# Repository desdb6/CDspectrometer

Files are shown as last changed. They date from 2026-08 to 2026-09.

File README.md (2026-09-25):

# CDspectrometer

A low-cost, portable circular dichroism (CD) spectrometer for measuring plasmonic chiral nanoparticles, built using a tungsten light source and a handheld CCD photospectrometer.

## Overview

Commercial CD spectrometers are dominated by a small number of manufacturers, making the technique costly and largely inaccessible to smaller laboratories, educational institutions, or field-based research. This project provides an open-source, low-cost, and easy-to-build alternative designed for daily benchtop use.

Rather than competing with the performance of high-end commercial instruments used for molecular chirality in biological systems, this design is focused on plasmonic chiral particles, prioritizing compactness, affordability, and ease of manufacturing and use.

## Repository Structure

| Folder | Contents |
|---|---|
| `Blender/` | 3D models and design files for the spectrometer housing/components |
| `STL/` | Printable STL files for 3D-printed parts |
| `CDcontrol_Python/` | Python code for device control |
| `Spectral_Composition/` | Python code for spectral data analysis |
| `Manuals/` | Build and operation manuals |
| `Experiments/` | Experimental data and test results |
| `Notes/` | Development notes |
| `LOG.md` | Project development log |

## Hardware Type

Measuring physical properties and in-lab sensors

## Keywords

Chiroptical spectroscopy, Circular dichroism, Plasmonic chiral nanoparticles

## License

This repository contains hardware designs and software, released under different open licenses:

- **Hardware designs** (`Blender/`, `STL/`) are licensed under [CERN-OHL-S 2.0](https://ohwr.org/cern_ohl_s_v2.txt). See `Blender/LICENSE` and `STL/LICENSE`.
- **Software** (`CDcontrol_Python/`, `Spectral_Composition/`) is licensed under the [MIT License](https://opensource.org/licenses/MIT). See `CDcontrol_Python/LICENSE` and `Spectral_Composition/LICENSE`.

## Citation

*(Add citation details once the associated HardwareX paper is published.)*

## Affiliation

CIC biomaGUNE, Basque Research and Technology Alliance (BRTA), Paseo Miramón 182, 20014 Donostia-San Sebastián, Gipuzkoa, Spain

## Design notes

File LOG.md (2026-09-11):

## Lab Report

### Monday 24/08/26

- 10:00 Visit: Tour Lab
- 11:30 Study components and install software
- 15:00 Make components list
- 15:30 Try to install Kinesis on CIC laptop, didn't work
- 17:30 Look in laser room for components
- 18:00 Test assembly

#### Notes

### Tuesday 25/08/26

- 9:00 3D print training
- 10:00 Try to install Kinesis on CIC laptop, works
- 11:00 Simple Python script to control motor
- 12:00 Fix spectrometer dlls
- 14:00 Design motor holder
- 15:30 Print holder motor
- 17:00 Work on spectral composition simulation

#### Notes

##### SDK software

The provided SDK example for the spectrometer is not working, I had to replace the dll file with the one installed with the SM32pro software. Also the provided code had to be debugged. The dll is 32 bit, so we need to use 32 bit Python, for which Python 3.11.7 is best. We also need to install compatible numpy (1.26.4), kiwisolver (1.4.7) and matplotlib (3.7.5) versions.

##### Spectral composition simulation

Spectral composition simulation is best done with Mueller calculus/matrices. There is no intensity graph for the light source, so model as a blackbody curve?

### Wednesday 26/08/2026

- 9:00 Design motor holder v2
- 11:30 Print motor holder v2
- 12:00 Read spectrometer software manual
- 13:00 Visit: Laser scattering experiment to determine particle population size via Brownian motion
- 14:00 Design cuvette holder
- 16:00 Write code to control spectrometer  
- 17:00 Work on spectral composition simulation

#### Notes

##### 3D printer holder

I have removed one of the walls as it was not actually supporting the motor.
  
#### Spectrometer software

It needs a light source pointed directly into the fiber, otherwise it is just random noise and increasing the integration time does nothing.

### Thursday 27/08/2026

- 9:00 Book 3D printer
- 9:10 Figure out spectrometer code example
- 10:15 Print cuvette holder
- 10:30 Continue spectrometer code example study
- 11:30 Visit: Laser scattering experiment to determine particle population size via Brownian motion
- 11:45 Continue spectrometer code example study
- 12:30 Write my own spectrometer control script
- 13:30 Assemble cuvette holder
- 14:45 Design cuvette holder second version
- 15:00 Print cuvette holder second version
- 15:15 Improve spectrometer control code
- 17:00 Assemble setup with new cuvette holder

#### Notes

### Friday 28/08/2026
- 9:00 Design flex collimator holder
- 10:00 Print flex collimator holder
- 10:30 Print flex collimator holder second version
- 11:00 Print flex cuvette holder
- 11:30 Design flex collimator holder on baseplate
- 12:00 Visit: Bio 3D printer

#### Notes

### Monday 31/08/2026
- 9:00 Design stronger cuvette holder
- 9:30 Print stronger cuvette holder
- 10:00 Meeting Luis
- 10:20 Brainstorm calibration ideas
- 11:00 Research printing material
- 12:00 Visit: CD spectrometer
- 13:30 Look at beam size
- 14:30 Make calibration code
- 15:00 Get calibration data from CD
- 16:00 Research enclosure
- 17:00 Design enclosure fit test print

#### Notes

##### Brainstorm what to do until light source arrives
- Calibration can be done using the Jasco CD: open the shutter and select a wavelength, then put fiber in front of beam and record a spectrum -> fit a cubic polynomial through data points
- Characterize linear polarizer and find fast axis angle using other linear polarizers
- Look at beam shape by using a second fiber and shining flash light through it before the motor
- Design an enclosure for setup in suitable material, Bionanoplasmonics has its own filaments but check with Gerard as well
- Also for cuvette holder, study what material is best (this part probably needs to be reprinted once we know the beam shape)
- Do a measurement at the Jasco CD to see how it is done

##### Optical parts 3D printing
The 3D prints ideally have to be 100% opaque. Usually, a matte black PLA is opaque enough for optical setups, there is black matte TPLA in the print room. If there is still too much scattering, options include:
- Using a specialized opaque PLA, but shipping is expensive + takes time
- Cover parts in candle soot
- Use black paper to block out light
- Use paint/spray to finish prints
- Optimize infill patterns for internal reflections

Useful blog post checking filament opacity: https://www.thingiverse.com/groups/3dp-photo/forums/general/topic:7227#google_vignette

Paper on print material opacity characterization: https://pmc.ncbi.nlm.nih.gov/articles/PMC8208549/

Github for open source optical microscope, simply uses matte black PLA: https://github.com/TadPath/PUMA

##### Open source optomechanical 3D prints
https://osf.io/9kt52/overview

https://journals.plos.org/plosone/article?id=10.1371/journal.pone.0059840

##### CCD photospectrometer calibration
We did this by basically using the Jasco CD as a monochromator, shining 10nm bandwidth light into the CCD fiber and noting the most intense pixel. The converstion from pixels to wavelengths is then done by fitting a cubic polynomial through the datapoints. The results show that the calibration hard coded into the SP python example is very wrong, and most likely not meant to be used for the SM440 photospectrometer; good that we checked this :)

### Tuesday 01/09/2026
- 9:00 Figure out time integration units
- 10:30 Print enclosure outline
- 11:15 Code live view and improve control panel buttons
- 12:30 Design enclosure fit test print second version
- 13:00 Light source arrived
- 13:30 Assembling setup
- 13:45 Testing spectrum measurements
- 15:00 Designing fast axis alignment experiment
- 17:00 Design collimator mount for light source
- 17:30 Look in LASER room for filters for fast axis alignment experiment

#### Notes

##### SP time integration units
I wrote a script to see what the conversion unit is between the inputted int time number and real time, as I couldn't make sense of it. The documentation said it is 10/3 us/count, but my script (time_int_testing.py) gives something very close to 50 us / count. I have built this into the spectrometer control script.

##### CCD dead pixel arrays
When testing the Tungsten light source, I noticed the spectrum shows a sharp dip at the same place every time, even without atmospheric interference. When shining a flash light we can see the same dip but smaller. My guess is that there are a few pixel rows with a worse quantum efficiency, or there is some other problem preventing these pixels from functioning correctly. Specifically, pixels 2046-2078 have this problem, corresponding to a spectral range of ~728nm-738nm.

##### Alignment experiment setup
We have to align the setup in at least two ways:
1. Rotation around the beam axis
2. Angle of incidence (has to be perpendicular to the surface of the optomechanical component)

Rotation around the beam axis: The fresnel rhomb retarder is difficult to align as it is not placed on a rotating mount. I think it is more practical to leave the fresnel rhomb retarder at an arbitrary angle (but near vertical), and to align the linear polariser on the motorized mount, which can be very accurately moved. We need to design an experiment where it is possible to find a maximum\minimum by changing only **one** setting (preferable the motor position).

I worked out the Mueller calculus and found a protocol that would work. We would put a second linear polariser behind the fresnel rhomb, work in the reference frame of the fast axis of the second polariser and define the angles $$\phi$$ and $$\theta$$ as the angles between the fast axes of the first linear polariser and fresnel rhomb respectively. The transmitted intensity for an unpolarised beam is then 

$$I(\theta, \phi) \propto \cos(2\theta)\cos(2(\theta-\phi))$$

We will align the two polarisers perpendicular to make the first cosine as big as possible to see big changes in intensity when changing $$\phi$$. We then make the second term zero by putting $$\phi$$ perpendicular to $$\theta$$. At this point we can simply subtract 45 degrees to put $$\phi$$ and $$\theta$$ at a 45 degree angle to make CPL.

### Wednesday 02/09/2026
- 9:00 Print front collimator holder
- 9:15 Make excel for fast axis alignment experiment
- 9:45 Setup experiment
- 10:15 Print opacity tool
- 10:30 Setup experiment
- 11:15 Print second front collimator holder
- 12:15 Visit: temporal resolution fluorescence spectrometer
- 13:00 Fast axis alignment measurements
- 14:30 3D print enclosure fit
- 17:00 Design new cuvette holder

#### Notes

##### Alignment experiment setup detector
I tried making the setup using a power and energy meter, but the noise due to temperature fluctuations seems to be too big. If I hold my hand in front of the detector or blow air, the noise is as big as 2-4x the signal. I have programmed a script (control_panel_alignment.py) to use the CCD to integrate the spectrum over a fixed range of wavelengths, which is less susceptible to noise.

Alignment to second linear polarizer: 5.1 degrees

Alignment to fresnel rhomb: 81.40 degrees

The excel crashed so I do not have the data from the first measurements anymore. I decided to automate the process in python for the data acquisition and simply look for the minimum.

### Thursday 03/09/2026
- 9:00 Print cuvette holder
- 9:30 Code broken pixel range indicator
- 10:00 Research CD formulas
- 10:30 Code absorbance and CD funtionalities
- 12:30 Debug code
- 13:30 Test measurement
- 15:00 Absorption spectra and make slides
- 16:00 Group meeting

#### Notes

##### To Do list until first prototype
In order of importance:

- Code Absorbance / CD spectrum functionalities
- Print new cuvette holder
- Design and print enclosure
- Reprint collimator holders
- Calculate/find handedness depending on angle
- Clean components

##### Absorption spectra
I tried to get some absorption spectra which look ok for the most part. I need to indicate the interval in which the light is intense enough to create a reliable signal, and also recheck the calibration as it seems to be off by around 20nm in the 700nm area. Luis provided me with minirods which show a peak at 750 on the commercial absorption spectrometer but 770nm in mine. However, the peak at 510nm lines up and the very first measurement I took did in fact show a peak at 750nm.

### Friday 03/09/2026
- 9:00 Design and print front collimator holder
- 9:45 Fix polarization convention
- 10:15 Design back collimator holder
- 10:45 CD measurement
- 11:00 Print back collimator holder
- 11:30 Beam alignment experiments (many)
- 14:30 Fabry Perot test

#### Notes
##### To Do list
- Print collimator holders to fix alignment
- Recalibrate 700nm wavelength range
- Program intensity cutoff indicator
- Measure more CD signals and look at oscillations

##### CD artefacts
Even without a sample, we get a significant CD signal. This could be cause by a number of things.

- The beam tilt: We can observe that the front collimator holder is slightly tilted which causes the beam to not travel parallel to the horizontal axis, but upwards. This could be due to removing the print from the printbed too fats which can cause warping. Later prints that were cooled down completely seemed to be aligned well. This tilt can mess with the polarization state as the incident angles for the total internal reflection will be different. Trying to align the beam gave results that are a little better in the 400-750nm range but worse around 1000nm. However trying to make the alignment worse by triyng to tilt the beam down a lot made it better overall.
- Fast axis alignment
- Dust on the linear polarizer: As the polariser turns, the beam will fall on a different spot on the polarizer which can cause differences in absorption
- There is a oscillating signal which looks to be linear with the frequency (also present without fresnel rhomb). My theory is that the beam is diffracting at the polarizer in a different way if the polarizer is horizontal and vertical, but I still need to test this.
- Fabry perot etalon somewhere

##### To Do for next week
- Clean the polarizer
- Figure out the CD artefacts
- Make program more user friendly: error handling, user guide etc
- Make icon for program
- Discuss journal?
- Design adjustable collimator holders
- Design smaller cuvette holder
- Make parts for UV-Vis absorption modular setup

### Monday 07/09/2026
- 9:00 Print front collimator holder
- 9:30 Test misalignments and figure out CD artefacts
- 10:30 Design and print fiber holder
- 11:00 Make code more user friendly
- 11:30 Rebuild setup
- 12:00 Turning collimator experiment
- 12:30 Print collimator holder
- 13:00 Make code more user friendly and make executable
- 15:00 Print fiber holder
- 15:30 Clean components
- 17:00 Realign components
- 17:30 Write user manual
- 18:00 More CD measurements

#### Notes
##### CD artefacts
I spent the morning trying and tweaking different components of the setup. The spectra I took can be found in the outputs folder for this date. Translation does not seem to make a great difference, but the rotation of the collimators seems to show a cosine-like effect on the overall intensity. This is true for **both** collimators, the front and the back. Rotating one of them also flips the CD spectra, but it is not as linear as I would have hoped. I decided to clean all the components to see if this is an improvement but for this the components also need to be realigned. In the end this did not seem to make a huge difference. Frustrating day :(

### Tuesday 08/09/2026
- 9:00 Design and print absorption spectroscopy cuvette holder
- 9:30 Rebuild setup
- 9:45 Try to recreate CD artefacts
- 11:00 Call Carlos
- 11:45 Program CD baseline correction
- 12:30 Recalibrate CCD
- 13:30 Absorption measurements
- 14:45 Print fiber holder
- 15:00 Program CD baseline correction, fix bugs, improve usability
- 15:30 Recalibration using Holmium oxide glass
- 16:00 Absorption measurements
- 16:30 Improve code usability
- 17:00 Helicoid CD measurements
- 17:30 Prepare overnight print

#### Notes
##### CD artefacts
The spectra I took can be found in the outputs folder for this date. My first idea today was to se a different polarizer and move it by hand, but this resulted in the same artefacts with a double peak, confirming the polarizer is not the problem. 

##### Call Carlos
Carlos said that it is known that the fiber position has a very big influence on the spectrum, and that it is very difficult to stabilize this. He suggests taking baseline measurements and correcting in software. Furthermore, if might be better to work in absorbance units. He also suggested a way to calibrate the CCD using a rare earth metal glass for small absorbance peaks. Finally he said we could be open to use free space light instead of fibers in the future.

### Wednesday 09/09/2026
- 9:00 Print cuvette holder
- 9:30 Figure sign flip out
- 11:00 Print cuvette holder
- 12:00 Helicoid CD measurements
- 13:00 Compare to Jasco CD
- 15:00 Compare data to Huu-Quang
- 15:30 Reduce noise in setup
- 17:30 Prepare overnight print

#### Notes

### Thursday 10/09/2026
- 9:00 (re-)Build absorbance and CD setups
- 9:30 Print collimator holder
- 10:00 Make plot buttons better
- 11:00 Cysteine CD measurements
- 11:30 Helicoid dilution experiment
- 12:30 Make group meeting slides
- 14:00 Absorption dilution experiment
- 16:00 Group meeting
- 17:00 Fix absorption baseline issue

#### Notes
##### Helicoid dilution experiment
To test the limit of what can be measured I will perform an experiment where I dilute the helicoid samples and see if I can still measure a CD signal. I will do dilutions of 1x, 5x, 25x and 125x. I do this by preparing dilutions by pipetting 30mul of the undiluted helicoids in a cuvette with 120mul of 1mM CTAB. Then I repeat this process 2 more times to make the other dilutions, making sure the sample is homogenous every time. I will take a baseline measurement before each CD measurement.

### Friday 11/09/2026
- 9:00 Final code changes

#### Notes
##### Pyinstaller command
"C:\Users\lguser\AppData\Local\Programs\Python\Python311-32\python.exe" -m PyInstaller --onefile --windowed --icon=cd.ico --add-data "SP_SDK;SP_SDK" main.py

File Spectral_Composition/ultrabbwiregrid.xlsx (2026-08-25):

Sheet: Transmission
 |  | Ultra Broadband Wire Grid Polarizers
 |  |  | Transmission (%)
 |  | Wavelength (nm) | Parallel | Perpendicular
 |  | 250 | 37.8124 | 0.80363
 |  | 251 | 38.88543 | 0.82579
 |  | 252 | 39.89029 | 0.83728
 |  | 253 | 40.83456 | 0.83963
Product Raw Data |  | 254 | 41.72528 | 0.83425
Wire Grid Polarizers: 300 nm - 3.2 µm |  | 255 | 42.56894 | 0.82242
 |  | 256 | 43.37153 | 0.80533
Item # | WPXXX-UB1 | 257 | 44.13853 | 0.78405
DISCLAIMER: The data presented here are typical. Slight variations in performance data will occur from lot to lot. Please contact Technical Support with any questions regarding the use or reliability of this data. |  | 258 | 44.87497 | 0.75956
 |  | 259 | 45.58542 | 0.73276
 |  | 260 | 46.27402 | 0.70444
 |  | 261 | 46.94451 | 0.6753
 |  | 262 | 47.60026 | 0.64599
 |  | 263 | 48.24424 | 0.61706
This data may be used in publications. However, please cite Thorlabs as the source. |  | 264 | 48.87909 | 0.58899
 |  | 265 | 49.50713 | 0.5622
 |  | 266 | 50.13036 | 0.53705
Additional Information: |  | 267 | 50.7505 | 0.51383
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

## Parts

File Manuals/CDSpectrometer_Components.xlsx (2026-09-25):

Product | Brand + model | Link | Comments
Light source | Sarspec LS-W14 Tungsten-Halogen Light Source | https://www.sarspec.com/products/light-sources/tungsten
Fibers | Sarspec Optical Fibers | https://www.sarspec.com/store/p/optical-fibers | I am unsure about the exact specifications (wavelength range, core diameter). We used two 100cm fibers, but shorter fibers would be more convenient.
Motorized mount | Thorlabs K10CR2/M Motorized Rotation Mount | https://www.thorlabs.com/item/K10CR2_M
Linear polarizer | Thorlabs WP25M-UB1 Mounted Wire Grid Polarizer | https://www.thorlabs.com/item/WP25M-UB1?aID=82b8f769d23edb5df1b9a876879e037c&aC=2
Fresnel rhomb | Thorlabs FR600QM Mounted Quarter-Wave Fresnel Rhomb Retarder | https://www.thorlabs.com/item/FR600QM?aID=6370abdd5eea46aaf2b5422b807dee97&aC=2
Collimators | BWTEK CLA-SMA Collimating Lens Assembly | https://m-oem.myshopify.com/products/collimating-lens-assembly-br-cla-sma | I am not sure if this is the website where the collimators where ordered from.
CCD photospectrometer | Spectral Products SM440 Handheld CCD Spectrometer | https://www.spectralproducts.com/SM240_440 | This was an old photospectrometer that the lab already had. Designing software for this spectrometer was challenging becuase it lacked documentation, but I have a working program now.
Breadboard | Thorlabs Solid Aluminum Optical Breadboards | https://www.thorlabs.com/solid-aluminum-optical-breadboards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
Fresnel rhomb mount | Thorlabs LMR1/M Lens Mount with Retaining Ring | https://www.thorlabs.com/item/LMR1_M?aID=360e756541fa952e6a85bb99a7f4f247&aC=2 | Was already in the lab
Retaining rings | Thorlabs SM1RR Retaining Ring | https://www.thorlabs.com/item/SM1RR | Was already in the lab
Optical post | Thorlabs TR30/M Optical Post | https://www.thorlabs.com/item/TR30_M?aID=8e9e7e1c5f374476b27a6275a6b0f033&aC=2 | Was already in the lab, unsure about exact height
Optical post mounting base | Thorlabs BA1/M Mounting Base | https://www.thorlabs.com/item/BA1_M | Was already in the lab

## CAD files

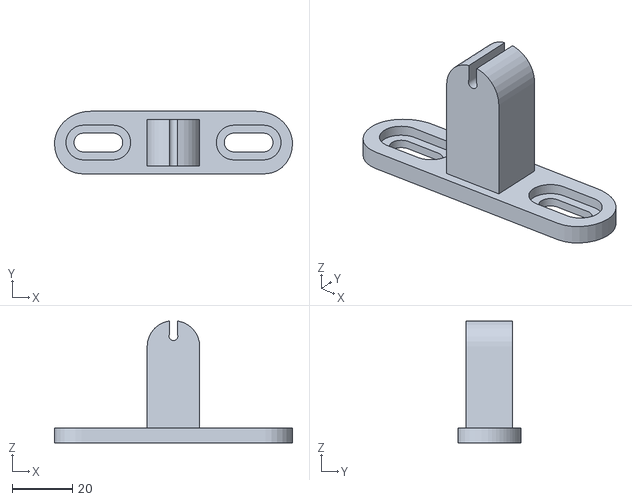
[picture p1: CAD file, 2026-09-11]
STL/20260910_UE3_Des_De_Borger_Fiber_Holder_Back_v2.stl
79.1 x 20.8 x 40.5

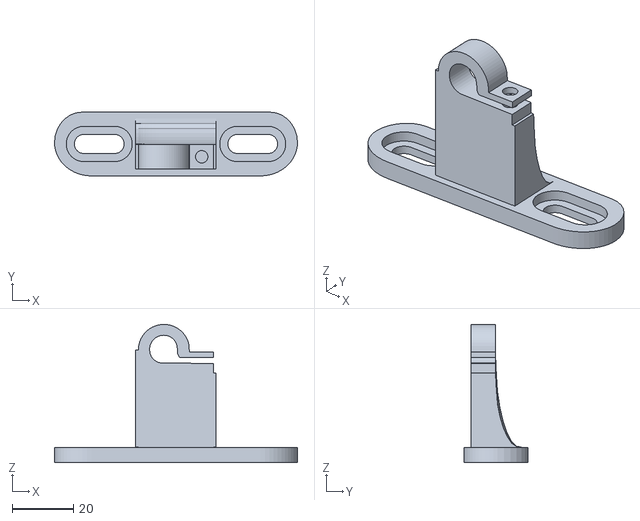
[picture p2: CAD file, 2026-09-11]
STL/20260910_UE3_Des_De_Borger_Collimator_Holder_v8.stl
79.1 x 20.8 x 45.0

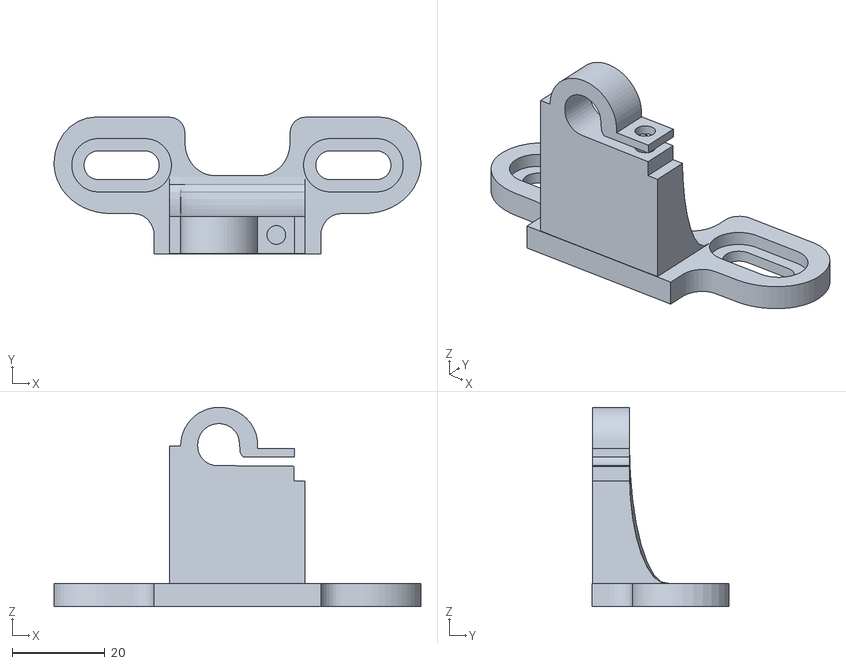
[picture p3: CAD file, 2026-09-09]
STL/20260908_UE3_Des_De_Borger_Collimator_Holder_v6.stl
79.1 x 29.5 x 43.0

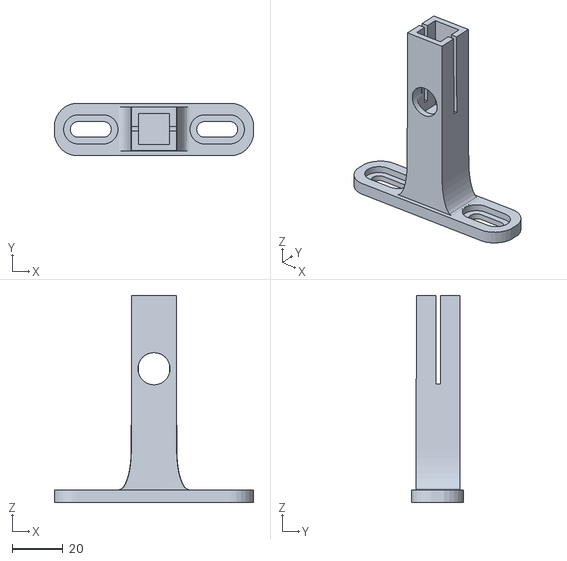
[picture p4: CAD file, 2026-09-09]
STL/20260908_UE3_Des_De_Borger_Cuvette_Holder_Absorption_v2.stl
78.7 x 20.7 x 82.0

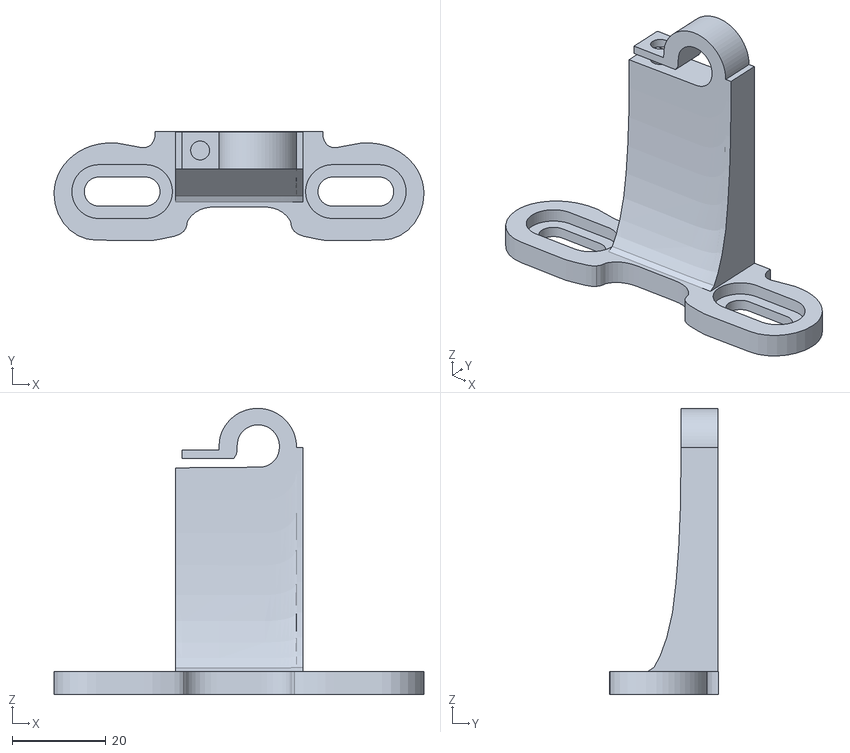
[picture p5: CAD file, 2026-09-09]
STL/20260908_UE3_Des_De_Borger_Collimator_Holder_Front_v3.stl
79.1 x 23.4 x 61.2

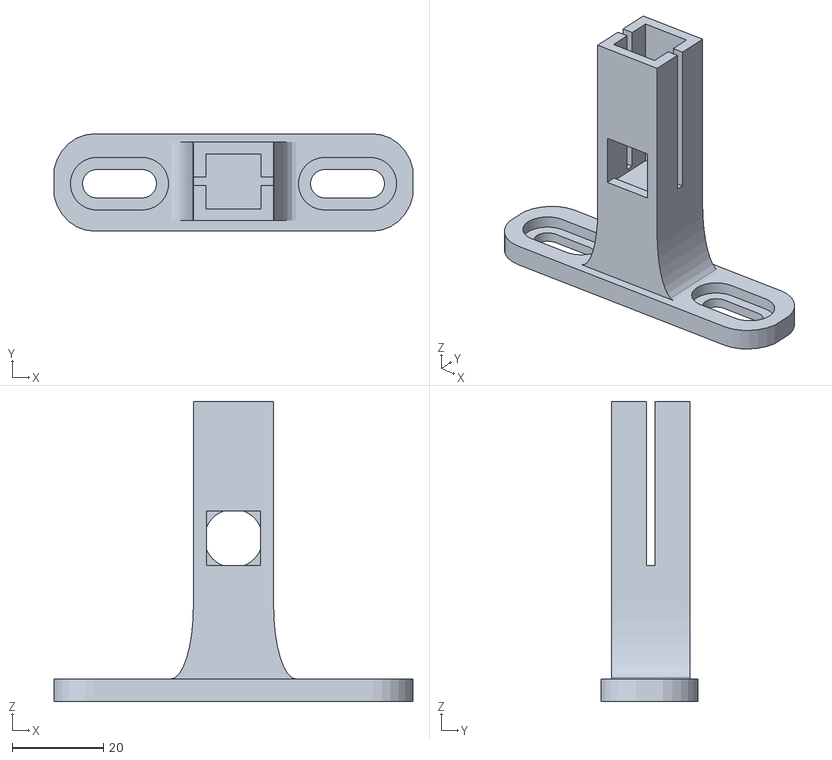
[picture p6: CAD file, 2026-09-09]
STL/20260908_UE3_Des_De_Borger_Cuvette_Holder_v5.stl
78.7 x 21.3 x 65.9

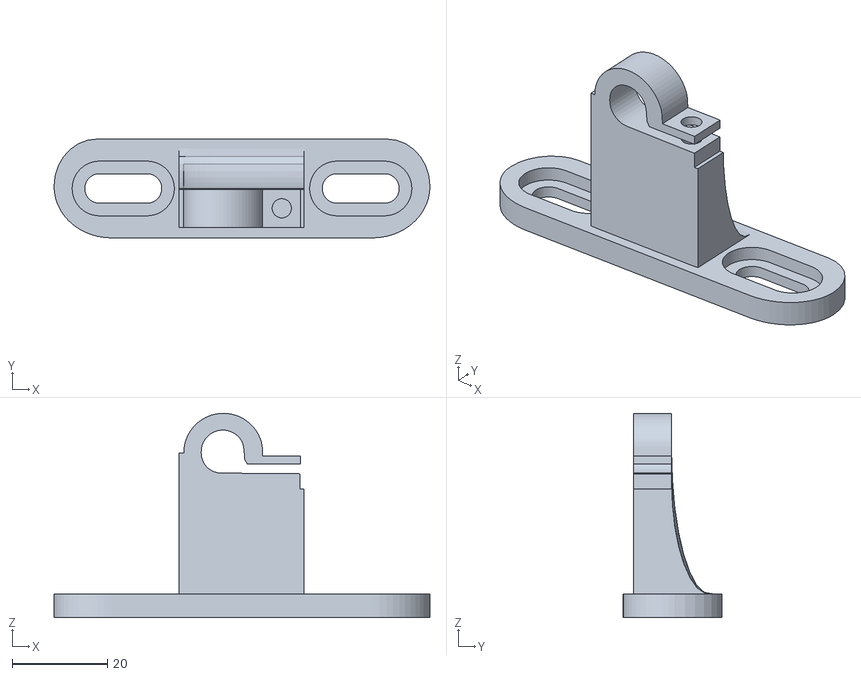
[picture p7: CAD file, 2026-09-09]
STL/20260909_UE3_Des_De_Borger_Collimator_Holder_v7.stl
79.1 x 20.8 x 43.0

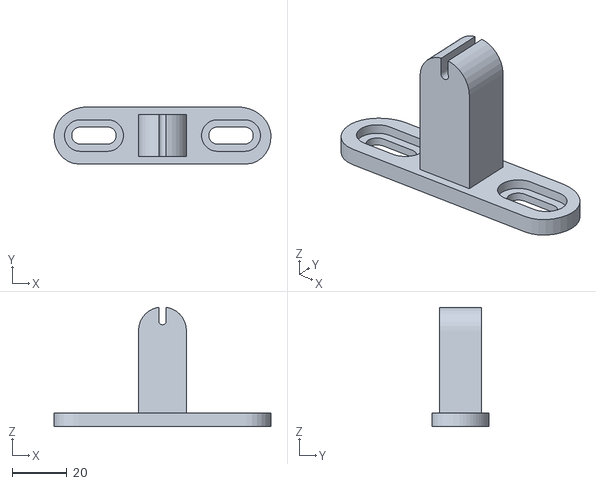
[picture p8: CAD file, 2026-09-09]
STL/20260908_UE3_Des_De_Borger_Fiber_Holder_Back_v1.stl
79.1 x 20.8 x 43.5

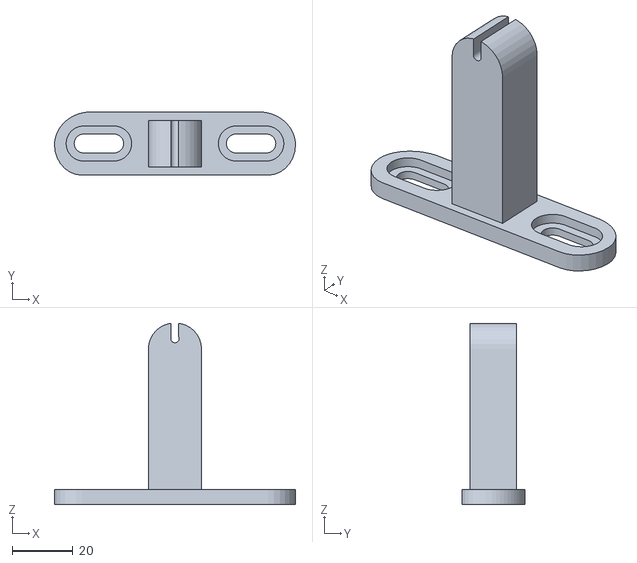
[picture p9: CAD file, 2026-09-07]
STL/20260907_UE3_Des_De_Borger_Fiber_Holder_Front_v2.stl
79.1 x 20.8 x 59.5

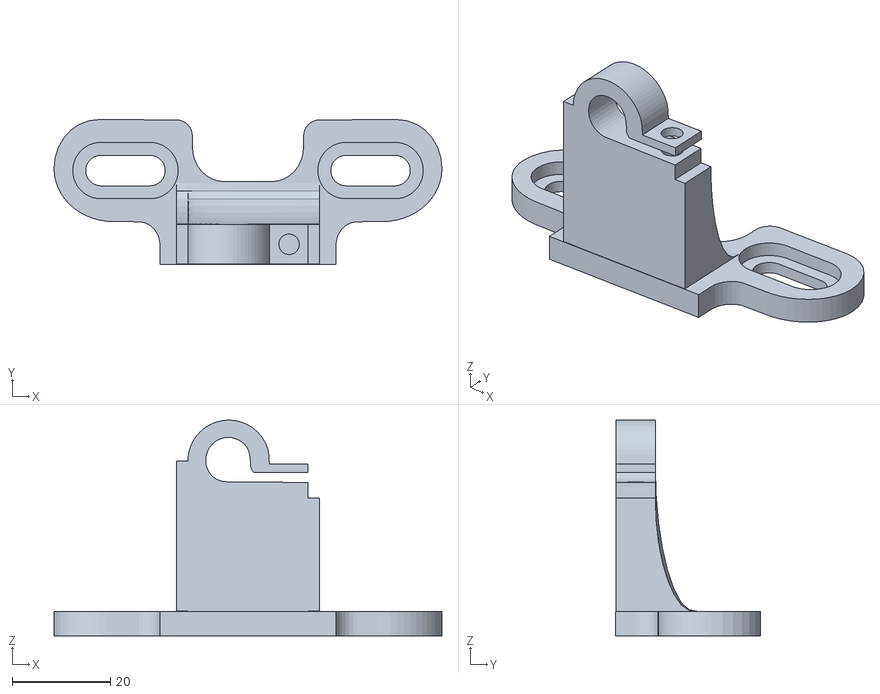
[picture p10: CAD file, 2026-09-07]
STL/20260904_UE3_Des_De_Borger_Collimator_Holder_v5.stl
79.1 x 29.5 x 44.0

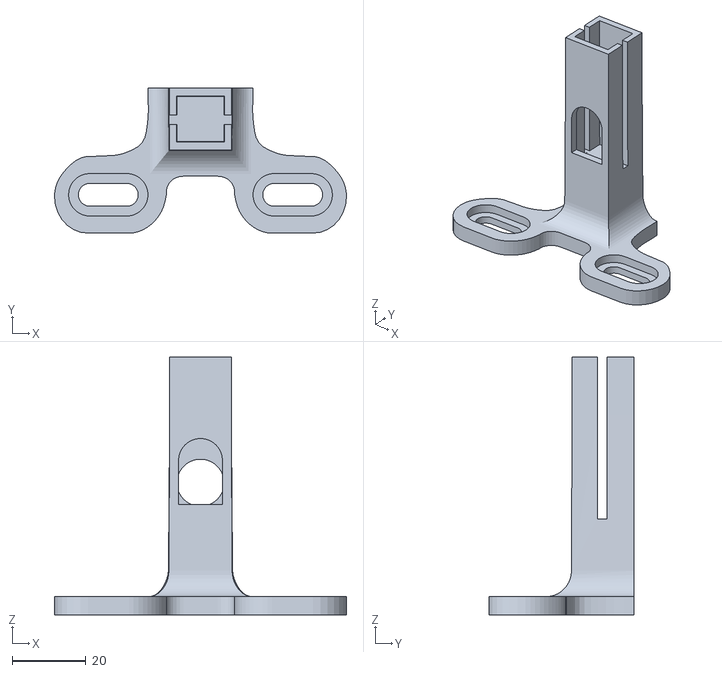
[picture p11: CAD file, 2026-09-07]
STL/20260902_UE3_Des_De_Borger_Cuvette_Holder_v4.stl
79.1 x 39.4 x 69.9

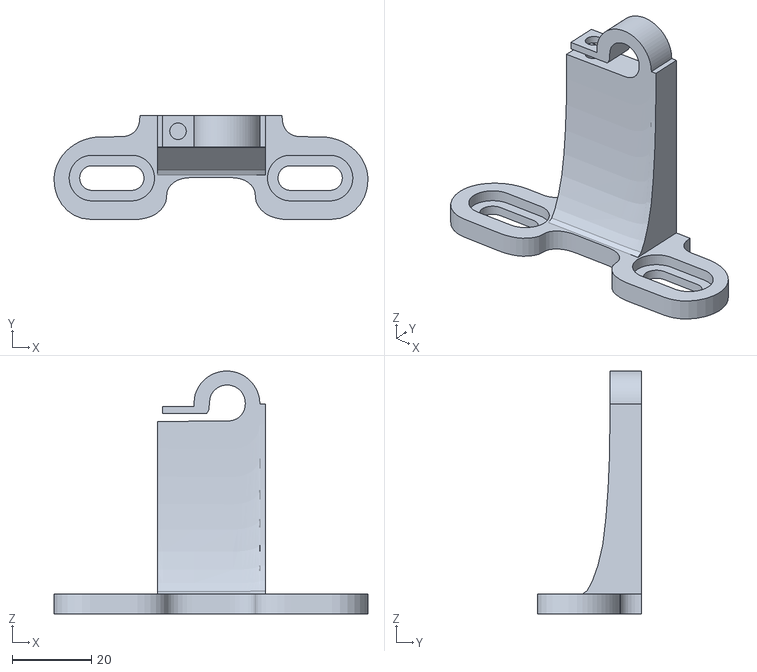
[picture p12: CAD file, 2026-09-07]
STL/20260904_UE3_Des_De_Borger_Collimator_Holder_Front_v2.stl
79.1 x 26.3 x 61.2

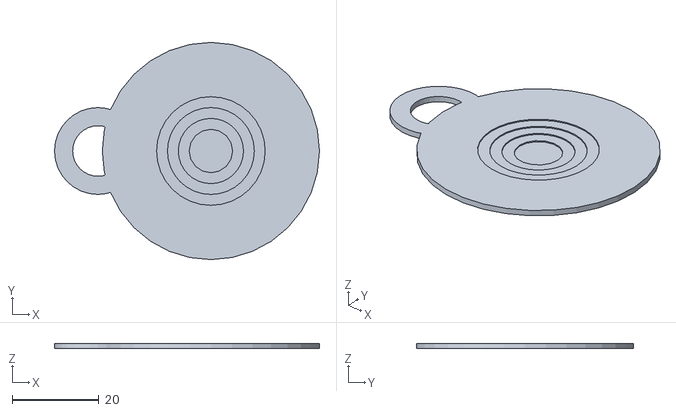
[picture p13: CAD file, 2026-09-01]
STL/20260901_UE3_Des_De_Borger_Opacity_Tool_v1.stl
61.0 x 50.0 x 1.25

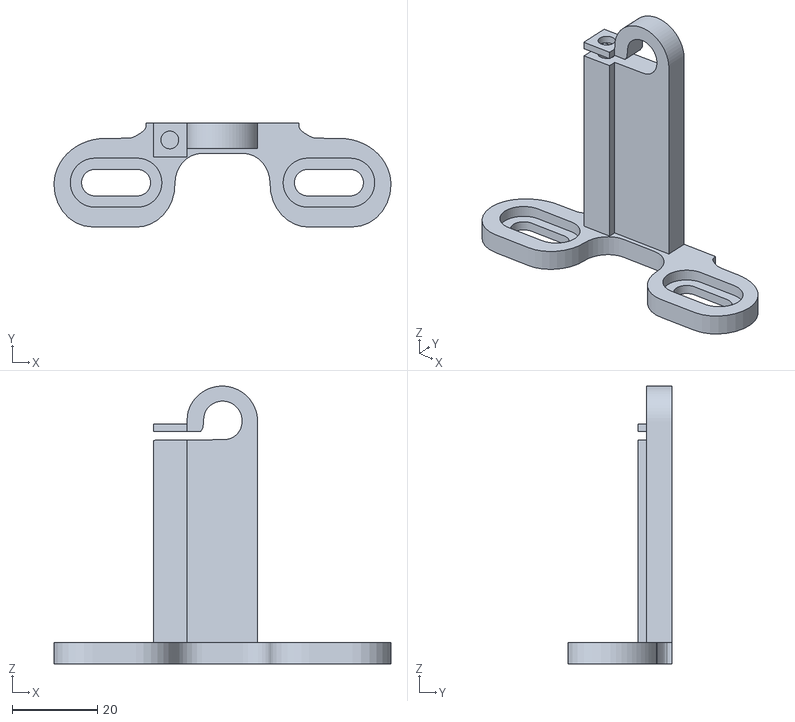
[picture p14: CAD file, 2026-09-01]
STL/20260901_UE3_Des_De_Borger_Collimator_Holder_Front_v1.stl
79.1 x 24.5 x 65.2

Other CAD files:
STL/20260909_UE3_Des_De_Borger_Cuvette_Holder_Absorption_v3.stl
STL/20260909_UE3_Des_De_Borger_Cuvette_Holder_v6.stl
STL/20260901_UE3_Des_De_Borger_Enclosure_v2.stl
STL/20260831_UE3_Des_De_Borger_Enclosure_v1.stl
Blender/Cuvette_Holder.blend
Blender/Cuvette_Holder_v3.blend
Blender/Enclosure.blend
Blender/Motor_Holder.blend
STL/20260825_UE3_Des_De_Borger_Motorized_Mount_Holder_v1.stl
STL/20260826_UE3_Des_De_Borger_Cuvette_Holder_v1.stl
STL/20260826_UE3_Des_De_Borger_Cuvette_Holder_v2.stl
STL/20260826_UE3_Des_De_Borger_Motorized_Mount_Holder_v2.stl
STL/20260828_UE3_Des_De_Borger_Collimator_Holder_v1.stl
STL/20260828_UE3_Des_De_Borger_Collimator_Holder_v2.stl
STL/20260828_UE3_Des_De_Borger_Collimator_Holder_v3.stl
STL/20260828_UE3_Des_De_Borger_Cuvette_Holder_v3.stl
STL/20260831_UE3_Des_De_Borger_Collimator_Holder_v4.stl
STL/20260831_UE3_Des_De_Borger_Cuvette_Holder_v4.stl
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

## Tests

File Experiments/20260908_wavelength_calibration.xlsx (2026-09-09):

Wavelength Calibration
Pixel Number (X) | Wavelength [nm] (Y) | Fitted Wavelength [nm] |  |  | Pixel Number (X) | Wavelength [nm] (Y) | Fitted Wavelength [nm] | Column1 | Column2
348 | 253.7 | 253.81 | a3 (x^3 coeff.) | -5.217523284e-09 | 1786 | 650 | 650.03 | a3 (x^3 coeff.) | -5.304768408e-09
465 | 313.2 | 312.88 | a2 (x^2 coeff.) | 0.000043 | 1708 | 627 | 627.18 | a2 (x^2 coeff.) | 0.000034
567 | 365 | 365.18 | a1 (x coeff.) | 0.472352 | 1631 | 604 | 604.71 | a1 (x coeff.) | 0.223703
643 | 404.7 | 404.62 | a0 (constant) | 84.423446 | 1504 | 568 | 567.84 | a0 (constant) | 173.177816
703 | 435.8 | 436.02 | R² (fit quality) | 0.999999 | 1425 | 545 | 545.07 | R² (fit quality) | 0.999999
910 | 546.1 | 546.10 |  |  | 1338 | 520 | 520.14
967 | 577 | 576.86 | N (points used) | 12 | 1248 | 495 | 494.56 | N (points used) | 4
971 | 579.1 | 579.03 |  |  | 1153 | 468 | 467.80
1186 | 696.5 | 696.68 |  |  | 1050 | 440 | 439.10
1306 | 763.5 | 763.36 |  |  | 608 | 320 | 320.46
1392 | 811.5 | 811.56 |  |  | 1442 | 550 | 549.96
1570 | 912.3 | 912.29 |  |  | 2643 | 900 | 902.00
 |  |  |  |  | 1892 | 680 | 681.18
 |  |  |  |  | 2025 | 720 | 720.38
 |  |  |  |  | 2096 | 740 | 741.33
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

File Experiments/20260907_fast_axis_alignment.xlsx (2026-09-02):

Cosine Fit for Fast Axis Alignment
Linear Polarisers
 |  |  |  |  | Fresnel Rhomb |  |  |  |  |  | Fresnel Rhomb |  |  |  |  |  | Fresnel Rhomb
Angle | Intensity | Fit | Fitted Parameters
0 | 6721075.59 | 6657926.769 | A | -3353972.081 | Angle | Intensity | Fit | Fitted Parameters |  |  | Angle | Intensity | Fit | Fitted Parameters |  |  | Angle | Intensity | Fit | Fitted Parameters
10 | 6296698.73 | 6254110.008 | θ | 84.85790885 | 0 | 6393676.671 | 6380044.592 | A | -3002454.143 |  | 75 | 536896.2906 | 582491.8416 | A | -3002454.143 |  | 81 | 462471.9667 | 460981.3665 | A
20 | 5524384.65 | 5500960.146 | C | 3357838.388 | 1 | 6364132.592 | 6348073.482 | θ | 81.61888595 | 81.61888595 | 75.1 | 534289.7684 | 580109.6853 | θ | 81.61888595 | 81.61888595 | 81.01 | 461668.1262 | 460951.626 | θ
30 | 4486114.55 | 4489318.17 |  |  | 2 | 6329076.313 | 6312638.727 | C | 3505165.231 |  | 75.2 | 531709.5824 | 577763.1699 | C | 3505165.231 |  | 81.02 | 461062.9683 | 460922.4463 | C
40 | 3300117.27 | 3341203.034 | Error |  | 3 | 6291499.046 | 6273783.497 |  |  |  | 75.3 | 529254.2796 | 575452.324 |  |  |  | 81.03 | 460907.2789 | 460893.8272
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

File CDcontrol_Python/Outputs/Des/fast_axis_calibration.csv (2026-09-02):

Angle | Area under curve
0.0 | 6393676.67103672
1.0 | 6364132.591771882
2.0 | 6329076.312562064
3.0 | 6291499.045962371
4.0 | 6248008.65282489
5.0 | 6206606.101648861
6.0 | 6160916.505734376
7.0 | 6115175.868107138
8.0 | 6065503.035573199
9.0 | 6012810.899548479
10.0 | 5951711.850099819
11.0 | 5890557.422278266
12.0 | 5825263.384138312
13.0 | 5755341.049465861
14.0 | 5684950.594220456
15.0 | 5610232.311723341
16.0 | 5531547.093792539
17.0 | 5450562.469517507
18.0 | 5365959.290085995
19.0 | 5279701.1895847805
20.0 | 5189303.485815058
21.0 | 5096137.761387564
22.0 | 5073747.941367077
23.0 | 5015255.243215982
24.0 | 4947027.270907387
25.0 | 5069108.947758417
26.0 | 4956911.838107316
27.0 | 4843975.348963841
28.0 | 4732492.2369612595
29.0 | 3454230.4719423996
30.0 | 4174883.1966920993
31.0 | 4140602.276940032
32.0 | 4034008.8586069383
33.0 | 4044703.909257674
34.0 | 3934809.798640431
35.0 | 3710000.9548274702
36.0 | 3512923.9067193014
37.0 | 3416243.6336829523
38.0 | 3316520.18033199
39.0 | 3213017.267754415
40.0 | 3108055.374543325
41.0 | 2999781.273060372
42.0 | 2889349.746831308
43.0 | 2783996.613392162
44.0 | 2683159.8578154016
45.0 | 2580050.8416984575
46.0 | 2479133.142878227
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

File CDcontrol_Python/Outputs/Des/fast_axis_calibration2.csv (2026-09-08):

Angle | Area under curve
0.0 | 8592177.337648764
1.0 | 8673519.117957883
2.0 | 8818534.764286347
3.0 | 8678935.334172152
4.0 | 8802990.38267034
5.0 | 8892673.503436912
6.0 | 8961485.314517168
7.0 | 9025558.898672892
8.0 | 9084240.421005853
9.0 | 9138349.538076613
10.0 | 9191394.950587008
11.0 | 9237067.278848153
12.0 | 9276248.033429813
13.0 | 9310452.696922734
14.0 | 9339942.808718957
15.0 | 9364677.770975718
16.0 | 9381909.894812746
17.0 | 9394274.496509647
18.0 | 9401123.664884694
19.0 | 9401322.479711095
20.0 | 9395321.520957626
21.0 | 9385456.853916334
22.0 | 9369639.559183968
23.0 | 9349041.686346259
24.0 | 9321526.212947488
25.0 | 9288280.838081017
26.0 | 9250653.822372302
27.0 | 9208014.706630252
28.0 | 9157029.447655885
29.0 | 9103563.841048818
30.0 | 9043337.96104439
31.0 | 8977481.6196399
32.0 | 8909091.397417873
33.0 | 8833685.951763436
34.0 | 8752022.10035578
35.0 | 8669679.811434552
36.0 | 8577972.802331934
37.0 | 8483539.028241992
38.0 | 8384954.151053939
39.0 | 8280508.478398395
40.0 | 8171620.644700295
41.0 | 8061304.627131857
42.0 | 7944352.084636467
43.0 | 7823606.927017244
44.0 | 7703104.620263263
45.0 | 7574020.41518002
46.0 | 7442799.91349121
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

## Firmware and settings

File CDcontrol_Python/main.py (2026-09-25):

"""
Class to draw tkinter gui to control SM440 handheld CCD and K10CR2 Thorlabs motorized mount
Author: Des De Borger
Last modified: 27/08/2026
"""

import threading
import os
import csv

import numpy as np
import matplotlib.pyplot as plt
from matplotlib.figure import Figure
from matplotlib.backends.backend_tkagg import FigureCanvasTkAgg
import tkinter as tk
from tkinter import messagebox

# from motor_control import K10CR2
from spectrometer_control import Spectrometer
from utils import *

# Offset angle where the linear polarizer and fresnel rhomb axes are aligned to each other. This is calibrated using alignment.py
OFFSET_FRESNEL_ANGLE = np.mod(107.41 - 90, 360)

# Dict for polarization angles
POL_DICT = {"Horizontal": 0, "Vertical": 90, "LHC": 45, "RHC": 315}

# Weak signal cutoff, shades absorption spectra
WEAK_SIGNAL_CUTOFF = 500

class ControlPanel(tk.Tk):
    def __init__(self):
        super().__init__()
        self.title("CD Spectrometer Control Panel")
        self.geometry("1400x850")
        self.current_dir = os.path.dirname(os.path.abspath(__file__))

        # Initialise spectra
        self.cur_spectrum = None

        self.ref_spectrum = None # Absorbance spectroscopy
        self.sample_spectrum = None
        self.abs_spectrum = None

        self.ref_lhc_intensities = None # CD spectroscopy
        self.ref_rhc_intensities = None
        self.lhc_intensities = None
        self.rhc_intensities = None
        self.cd_ref_spectrum = None
        self.cd_ref_spectrum_mdeg = None
        self.cd_spectrum = None
        self.cd_spectrum_millideg = None
        self.avg_abs_spectrum = None
        self.g_factor = None

        # Flag for current spectrum kind
        self.cur_spectrum_kind = None

        # Flags for clickable buttons
        self.motor_buttons_active = True
        self.spectrometer_buttons_active = True

        # Flags for busy components
        self.motor_moving = False
        self.spectrometer_busy = False

        # Flag for dark count
        self.dark_count_subtracted = False

        # Left column: control panels
        self.controls_frame = tk.Frame(self)
        self.controls_frame.pack(side="left", fill="y", padx=5, pady=5)

        # Right column: live view plot
        self.plot_frame = tk.Frame(self)
        self.plot_frame.pack(side="right", fill="both", expand=True, padx=5, pady=5)

        try:
            self.spec = Spectrometer()
        except Exception as e:
            self.spec = None
            messagebox.showwarning("Spectrometer not connected", f"Could not connect to spectrometer:\n{e}")

        try:
            self.motor = K10CR2("55547014")
        except Exception as e:
            self.motor = None
            messagebox.showwarning("Motorized mount not connected", f"Could not connect to motor:\n{e}")

        # ------------------------------------------------------------------
        # Connect Devices
        # ------------------------------------------------------------------
        self.connection_panel = tk.LabelFrame(self.controls_frame, text="Connect Devices")
        self.connection_panel.pack(padx=10, pady=5, fill="both")

        self.connect_motor_btn = tk.Button(self.connection_panel, text="Connect Motor", command=self.connect_motor)
        self.connect_motor_btn.grid(row=0, column=0, padx=10, pady=5, sticky="ew")

        self.connect_spec_btn = tk.Button(self.connection_panel, text="Connect Spectrometer", command=self.connect_spectrometer)
        self.connect_spec_btn.grid(row=0, column=1, padx=10, pady=5, sticky="ew")

        self.status_var = tk.StringVar(value="Ready")
        self.status_label = tk.Label(
            self.connection_panel, textvariable=self.status_var,
            anchor="w", fg="#444444"
            )
        self.status_label.grid(row=0, column=2, padx=10, pady=5, sticky="ew")

        # Let the status column absorb extra horizontal space rather than the buttons stretching
        self.connection_panel.grid_columnconfigure(2, weight=1)

        # ------------------------------------------------------------------
        # Motor Control
        # ------------------------------------------------------------------
        self.motor_control_panel = tk.LabelFrame(self.controls_frame, text="K10CR2 Motorized Mount Control")
        self.motor_control_panel.pack(padx=10, pady=5, fill="both")

        # -- Manual Control sub-panel --
        self.motor_manual_control_panel = tk.LabelFrame(self.motor_control_panel, text="Manual Control Actions")
        self.motor_manual_control_panel.grid(row=0, column=0, padx=8, pady=4, sticky="ew")

        self.move_position_label = tk.Label(self.motor_manual_control_panel, text="Position (deg):")
        self.move_position_label.grid(row=0, column=0, padx=10, pady=5, sticky="w")

        self.move_position_entry = tk.Entry(self.motor_manual_control_panel)
        self.move_position_entry.grid(row=0, column=1, padx=10, pady=5, sticky="ew")
        self.move_position_entry.insert(0, "0")

        self.home_motor_button = tk.Button(self.motor_manual_control_panel, text="Home Motor", command=self.home_motor_click)
        self.home_motor_button.grid(row=1, column=0, padx=10, pady=5, sticky="ew")

        self.move_motor_button = tk.Button(self.motor_manual_control_panel, text="Move", command=self.move_motor_click)
        self.move_motor_button.grid(row=1, column=1, padx=10, pady=5, sticky="ew")

        # -- Polarization sub-panel --
        self.motor_polarization_panel = tk.LabelFrame(self.motor_control_panel, text="Polarization Actions")
        self.motor_polarization_panel.grid(row=1, column=0, padx=8, pady=4, sticky="ew")

        self.alignment_angle_label = tk.Label(self.motor_polarization_panel, text="Offset angle (deg):")
        self.alignment_angle_label.grid(row=0, column=2, padx=10, pady=5, sticky="w")

        self.alignment_angle_show_box = tk.Entry(self.motor_polarization_panel, width=8)
        self.alignment_angle_show_box.grid(row=1, column=2, padx=10, pady=5, sticky="ew")
        self.alignment_angle_show_box.insert(0, OFFSET_FRESNEL_ANGLE)
        self.alignment_angle_show_box.config(state="readonly")

        self.hor_pol_button = tk.Button(self.motor_polarization_panel, text="Horizontal", command=lambda: self.move_motor_polarization(pol="Horizontal"))
        self.hor_pol_button.grid(row=0, column=0, padx=10, pady=5, sticky="ew")

        self.vert_pol_button = tk.Button(self.motor_polarization_panel, text="Vertical", command=lambda: self.move_motor_polarization(pol="Vertical"))
        self.vert_pol_button.grid(row=0, column=1, padx=10, pady=5, sticky="ew")

        self.lhc_pol_button = tk.Button(self.motor_polarization_panel, text="LHC", command=lambda: self.move_motor_polarization(pol="LHC"))
        self.lhc_pol_button.grid(row=1, column=0, padx=10, pady=5, sticky="ew")

        self.rhc_pol_button = tk.Button(self.motor_polarization_panel, text="RHC", command=lambda: self.move_motor_polarization(pol="RHC"))
        self.rhc_pol_button.grid(row=1, column=1, padx=10, pady=5, sticky="ew")

        # ------------------------------------------------------------------
        # Spectrometer Control
        # ------------------------------------------------------------------
        self.t_int_val = 30
        self.t_avg_val = 1

        self.spectrometer_panel = tk.LabelFrame(self.controls_frame, text="SM440 Handheld CCD Control")
        self.spectrometer_panel.pack(padx=10, pady=5, fill="both")

        # -- Settings sub-panel --
        self.settings_panel = tk.LabelFrame(self.spectrometer_panel, text="Settings")
        self.settings_panel.grid(row=0, column=0, padx=8, pady=(8, 4), sticky="ew")

        self.int_time_label = tk.Label(self.settings_panel, text="Integration Time (ms):")
        self.int_time_label.grid(row=0, column=0, padx=8, pady=5, sticky="w")

        self.int_time_entry = tk.Entry(self.settings_panel)
        self.int_time_entry.grid(row=0, column=1, padx=8, pady=5, sticky="ew")
        self.int_time_entry.insert(0, "30")
        self.int_time_entry.bind("<Return>", self.set_spectrometer_settings_click)

        self.int_time_show_box = tk.Entry(self.settings_panel, state="readonly", width=8)
        self.int_time_show_box.grid(row=0, column=2, padx=8, pady=5, sticky="ew")

        self.time_avg_label = tk.Label(self.settings_panel, text="Time Average:")
        self.time_avg_label.grid(row=1, column=0, padx=8, pady=5, sticky="w")

        self.time_avg_entry = tk.Entry(self.settings_panel)
        self.time_avg_entry.grid(row=1, column=1, padx=8, pady=5, sticky="ew")
        self.time_avg_entry.insert(0, "1")
        self.time_avg_entry.bind("<Return>", self.set_spectrometer_settings_click)

        self.time_avg_show_box = tk.Entry(self.settings_panel, state="readonly", width=8)
        self.time_avg_show_box.grid(row=1, column=2, padx=8, pady=5, sticky="ew")

        self.set_settings_btn = tk.Button(self.settings_panel, text="Set", command=self.set_spectrometer_settings_click)
        self.set_settings_btn.grid(row=0, column=3, rowspan=2, padx=8, pady=5, sticky="ns")

        # -- Actions sub-panel --
        self.actions_panel = tk.LabelFrame(self.spectrometer_panel, text="Actions")
        self.actions_panel.grid(row=1, column=0, padx=8, pady=4, sticky="ew")

        self.measure_spectrum = tk.Button(self.actions_panel, text="Measure Reference Spectrum", command=self.measure_spectrum_click)
        self.measure_spectrum.grid(row=0, column=0, padx=8, pady=5, sticky="ew")

        self.dark_count_btn = tk.Button(self.actions_panel, text="Subtract Dark Counts", command=self.measure_dark_count)
        self.dark_count_btn.grid(row=0, column=1, padx=8, pady=5, sticky="ew")

        self.live_view_btn = tk.Button(self.actions_panel, text="Start Live View", command=self.toggle_live_view)
        self.live_view_btn.grid(row=0, column=2, padx=8, pady=5, sticky="ew")

        # self.show_max_btn = tk.Button(self.actions_panel, text="Display Maximum Value Pixel", command=self.show_max_val_pixel)
        # self.show_max_btn.grid(row=1, column=1, padx=8, pady=5, sticky="ew")

        # -- Absorbance sub-panel --
        self.absorbance_panel = tk.LabelFrame(self.spectrometer_panel, text="Absorbance")
        self.absorbance_panel.grid(row=2, column=0, padx=8, pady=4, sticky="ew")

        self.measure_absorbance_spectrum = tk.Button(self.absorbance_panel, text="Measure Absorbance Spectrum", command=self.measure_absorbance_spectrum_click)
        self.measure_absorbance_spectrum.grid(row=0, column=0, padx=8, pady=5, sticky="ew")

        # -- CD sub-panel --
        self.cd_panel = tk.LabelFrame(self.spectrometer_panel, text="Circular Dichroism")
        self.cd_panel.grid(row=3, column=0, padx=8, pady=4, sticky="ew")

        self.cd_cycles_label = tk.Label(self.cd_panel, text="# Cycles:")
        self.cd_cycles_label.grid(row=0, column=0, padx=8, pady=5, sticky="w")

        self.cd_cycles_entry = tk.Entry(self.cd_panel)
        self.cd_cycles_entry.grid(row=0, column=1, padx=8, pady=5, sticky="ew")
        self.cd_cycles_entry.insert(0, "1")
        self.cd_cycles_entry.bind("<Return>", self.set_cd_settings_click)

        self.cd_cycles_show_box = tk.Entry(self.cd_panel, state="readonly", width=8)
        self.cd_cycles_show_box.grid(row=0, column=2, padx=8, pady=5, sticky="ew")

        self.cd_cycles_btn = tk.Button(self.cd_panel, text="Set", command=self.set_cd_settings_click)
        self.cd_cycles_btn.grid(row=0, column=3, padx=8, pady=5, sticky="ns")

        self.measure_cd_reference_btn = tk.Button(self.cd_panel, text="Measure CD Reference", command=self.measure_cd_reference_click)
        self.measure_cd_reference_btn.grid(row=1, column=0, padx=8, pady=5, sticky="ew")

        self.measure_cd_spectrum_btn = tk.Button(self.cd_panel, text="Measure CD Spectrum", command=self.measure_cd_spectrum_click)
        self.measure_cd_spectrum_btn.grid(row=1, column=1, padx=8, pady=5, sticky="ew")

        # ------------------------------------------------------------------
        # Save Panel
        # ------------------------------------------------------------------
        self.save_panel = tk.LabelFrame(self.controls_frame, text="Save")
        self.save_panel.pack(padx=8, pady=(4, 8), fill="both")

        self.filename_label = tk.Label(self.save_panel, text="Filename:")
        self.filename_label.grid(row=0, column=0, padx=8, pady=5, sticky="w")

        self.filename_entry = tk.Entry(self.save_panel)
        self.filename_entry.grid(row=0, column=1, columnspan=2, padx=8, pady=5, sticky="ew")
        self.filename_entry.insert(0, "spectrum")

        self.save_spectrum_btn = tk.Button(self.save_panel, text="Save Spectrum Data", command=self.save_data_spectrum_click)
        self.save_spectrum_btn.grid(row=0, column=3, padx=8, pady=5, sticky="ew")

        # ------------------------------------------------------------------
        # Save Panel
        # ------------------------------------------------------------------
        self.plot_panel = tk.LabelFrame(self.controls_frame, text="Plot")
        self.plot_panel.pack(padx=8, pady=(4, 8), fill="both")

        self.plot_ref_btn = tk.Button(self.plot_panel, text="Ref.", command=self.save_plot_ref_click)
        self.plot_ref_btn.grid(row=0, column=0, padx=8, pady=5, sticky="ew")

        self.plot_abs_btn = tk.Button(self.plot_panel, text="Abs.", command=self.save_plot_abs_click)
        self.plot_abs_btn.grid(row=0, column=1, padx=8, pady=5, sticky="ew")

        self.plot_abs_btn = tk.Button(self.plot_panel, text="CD Abs.", command=self.save_plot_avg_abs_click)
        self.plot_abs_btn.grid(row=0, column=2, padx=8, pady=5, sticky="ew")

        self.plot_cd_ref_btn = tk.Button(self.plot_panel, text="CD baseline (mdeg)", command=self.save_plot_cd_ref_click)
        self.plot_cd_ref_btn.grid(row=0, column=3, padx=8, pady=5, sticky="ew")

        # self.plot_cd_btn = tk.Button(self.plot_panel, text="CD (abs)", command=self.save_plot_cd_click)
        # self.plot_cd_btn.grid(row=0, column=4, padx=8, pady=5, sticky="ew")

        self.plot_ellipticity_btn = tk.Button(self.plot_panel, text="CD (mdeg)", command=self.save_plot_ellipticity_click)
        self.plot_ellipticity_btn.grid(row=0, column=4, padx=8, pady=5, sticky="ew")

        self.plot_g_factor_btn = tk.Button(self.plot_panel, text="g-factor", command=self.save_plot_g_factor_click)
        self.plot_g_factor_btn.grid(row=0, column=5, padx=8, pady=5, sticky="ew")

        # ------------------------------------------------------------------
        # Live Spectrometer View
        # ------------------------------------------------------------------
        self.live_view_active = False

        self.fig = Figure(figsize=(5.5, 3), dpi=100)
        self.ax = self.fig.add_subplot(111)
        self.line, = self.ax.plot([], [], color="#2563eb", linewidth=1.2)
        self.ax.set_title("Live Spectrophotometer View", fontsize=14)
        self.ax.set_xlabel("Wavelength (nm)")
        self.ax.set_ylabel("Intensity (counts)")
        self.ax.grid(True, linestyle="--", alpha=0.4)

        try:
            self.ax.set_xlim(np.min(self.spec.wavelengths), np.max(self.spec.wavelengths))
            self.ax.set_ylim(0, 2 ** 16)

            if self.spec.broken_wavelength_range is not None:
                self.ax.fill_between(
                    self.spec.wavelengths, 0, 2 ** 16,
                    where=self.spec.broken_wavelength_mask,
                    color="#ff3838", alpha=0.5,
                    label='Malfunctioning pixel range'
                    )
                self.ax.legend(fontsize=6)
        except AttributeError:
            # self.spec is None or missing expected attributes (not connected)
            self.ax.set_xlim(0, 1)
            self.ax.set_ylim(0, 1)
            self.ax.text(
                0.5, 0.5, "Spectrometer not connected",
                ha="center", va="center", transform=self.ax.transAxes,
                fontsize=11, color="#888888"
                )

        self.canvas = FigureCanvasTkAgg(self.fig, master=self.plot_frame)
        self.canvas.get_tk_widget().pack(padx=10, pady=10, fill="both", expand=True)

        # Home motor
        if self.motor is not None:
            self.home_motor_click()

        # Set initial settings
        if self.spec is not None:
            self.set_spectrometer_settings_click()
        self.set_cd_settings_click()

        # Turn off buttons if not connected
        if self.motor is None:
            self.motor_buttons_active = True   # set to true, toggle turns it to false
            self.toggle_motor_buttons()

        if self.spec is None:
            self.spectrometer_buttons_active = True
            self.toggle_spectrometer_buttons()

    # ------------------------------------------------------------------
    # Toggle methods
    # ------------------------------------------------------------------

    def toggle_motor_buttons(self):
        if self.motor_buttons_active:
            self.move_motor_button.config(state="disabled")
            self.home_motor_button.config(state="disabled")
            self.hor_pol_button.config(state="disabled")
            self.vert_pol_button.config(state="disabled")
            self.lhc_pol_button.config(state="disabled")
            self.rhc_pol_button.config(state="disabled")
            self.motor_buttons_active = False
        elif not self.motor_buttons_active:
            self.move_motor_button.config(state="normal")
            self.home_motor_button.config(state="normal")
            self.hor_pol_button.config(state="normal")
            self.vert_pol_button.config(state="normal")
            self.lhc_pol_button.config(state="normal")
            self.rhc_pol_button.config(state="normal")
            self.motor_buttons_active = True

    def toggle_spectrometer_buttons(self):
        if self.spectrometer_buttons_active:
            self.measure_spectrum.config(state="disabled")
            self.dark_count_btn.config(state="disabled")
            self.live_view_btn.config(state="disabled")
            self.measure_absorbance_spectrum.config(state="disabled")
            self.measure_cd_spectrum_btn.config(state="disabled")
            self.measure_cd_reference_btn.config(state="disabled")
            self.spectrometer_buttons_active = False
        elif not self.spectrometer_buttons_active:
            self.measure_spectrum.config(state="normal")
            self.dark_count_btn.config(state="normal")
            self.live_view_btn.config(state="normal")
            self.measure_absorbance_spectrum.config(state="normal")
            self.measure_cd_spectrum_btn.config(state="normal")
            self.measure_cd_reference_btn.config(state="normal")
            self.spectrometer_buttons_active = True

    # ------------------------------------------------------------------
    # Connect methods
    # ------------------------------------------------------------------

    def connect_motor(self):
        try:
            self.motor = K10CR2("55547014")
        except Exception as e:
            self.motor = None
            messagebox.showerror("Error", f"Could not connect to motor:\n{e}")
            return

        self.set_status("Succesfully connected motor.")

        if not self.motor_buttons_active:
            self.toggle_motor_buttons()

    def connect_spectrometer(self):
        try:
            self.spec = Spectrometer()
        except Exception as e:
            self.spec = None
            messagebox.showerror("Error", f"Could not connect to spectrometer:\n{e}")
            return

        if not self.spectrometer_buttons_active:
            self.toggle_spectrometer_buttons()

        self.set_status("Succesfully connected spectrometer.")

        # Refresh the live-view plot now that self.spec is populated
        self.ax.clear()
        self.line, = self.ax.plot([], [], color="#2563eb", linewidth=1.2)
        self.ax.set_title("Live Spectrophotometer View", fontsize=14)
        self.ax.set_xlabel("Wavelength (nm)")
        self.ax.set_ylabel("Intensity (counts)")
        self.ax.grid(True, linestyle="--", alpha=0.4)
        self.ax.set_xlim(np.min(self.spec.wavelengths), np.max(self.spec.wavelengths))
        self.ax.set_ylim(0, 2 ** 16)

        if self.spec.broken_wavelength_range is not None:
            self.ax.fill_between(
                self.spec.wavelengths, 0, 2 ** 16,
                where=self.spec.broken_wavelength_mask,
                color="#ff3838", alpha=0.5,
                label='Malfunctioning pixel range'
                )
            self.ax.legend(fontsize=6)

        self.canvas.draw_idle()

    def set_status(self, text: str):
        """Thread-safe status update — always routes through the Tk main loop."""
        self.after(0, lambda: self.status_var.set(text))

    # ------------------------------------------------------------------
    # Motor control methods
    # ------------------------------------------------------------------

    def home_motor_click(self):
        if self.motor_moving:
            return  # ignore clicks while a move is already in progress

        self.motor_moving = True
        self.toggle_motor_buttons()

        def worker():
            try:
                self.set_status("Homing motor....")
                self.motor.home()
            finally:
                self.motor_moving = False
                self.after(0, self.toggle_motor_buttons)
                self.set_status("Motor homed")

        threading.Thread(target=worker, daemon=True).start()
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

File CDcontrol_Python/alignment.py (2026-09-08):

"""
Script for aligning the fast axis of the Fresnel Rhomb with the polarisation axis of the linear polariser
Last modified: 27/08/2026
"""

import threading

import numpy as np
import matplotlib.pyplot as plt
from matplotlib.figure import Figure
from matplotlib.backends.backend_tkagg import FigureCanvasTkAgg
import tkinter as tk
from tkinter import messagebox
import csv

from motor_control import K10CR2
from spectrometer_control import Spectrometer

class ControlPanel(tk.Tk):
    def __init__(self):
        super().__init__()
        self.title("CD Spectrometer Control Panel")
        self.geometry("1150x560")  # widen the window to fit both columns

        # Left column: holds all existing control panels
        self.controls_frame = tk.Frame(self)
        self.controls_frame.pack(side="left", fill="y", padx=5, pady=5)

        # Right column: live view plot
        self.plot_frame = tk.Frame(self)
        self.plot_frame.pack(side="right", fill="both", expand=True, padx=5, pady=5)

        try:
            self.spec = Spectrometer()
        except Exception as e:
            print(f"Error connecting spectrometer: {e}")

        try:
            self.motor = K10CR2("55547014")
        except Exception as e:
            print(f"Error connecting motor: {e}") 

        # Connect devices
        self.connection_panel = tk.LabelFrame(self.controls_frame, text="Connect Devices")
        self.connection_panel.pack(padx=10, pady=10, fill="both")

        self.connect_motor_btn = tk.Button(self.connection_panel, text="Connect Motor", command=self.connect_motor)
        self.connect_motor_btn.grid(row=0, column=0, padx=10, pady=5)

        self.connect_spec_btn = tk.Button(self.connection_panel, text="Connect Spectrometer", command=self.connect_spectrometer)
        self.connect_spec_btn.grid(row=0, column=1, padx=10, pady=5)

        # Motor Control
        self.motor_moving = False

        self.motor_control_panel = tk.LabelFrame(self.controls_frame, text="K10CR2 Motorized Mount Control")
        self.motor_control_panel.pack(padx=10, pady=10, fill="both")

        self.home_motor = tk.Button(self.motor_control_panel, text="Home Motor", command=self.motor.home)
        self.home_motor.grid(row=0, column=0, padx=10, pady=5)

        self.move_position_entry = tk.Entry(self.motor_control_panel)
        self.move_position_entry.grid(row=1, column=1, padx=10, pady=5, sticky="ew")
        self.move_position_entry.insert(0, "0")

        self.move_motor_button = tk.Button(self.motor_control_panel, text="Move", command=self.move_motor_click)
        self.move_motor_button.grid(row=1, column=0, padx=10, pady=5)

        # Spectrometer Control
        self.spectrometer_panel = tk.LabelFrame(self.controls_frame, text="SM440 Handheld CCD Control")
        self.spectrometer_panel.pack(padx=10, pady=10, fill="both")

        self.int_time_label = tk.Label(self.spectrometer_panel, text="Set Integration Time (ms):")
        self.int_time_label.grid(row=0, column=0, padx=10, pady=5)

        self.int_time_entry = tk.Entry(self.spectrometer_panel)
        self.int_time_entry.grid(row=0, column=1, padx=10, pady=5, sticky="ew")
        self.int_time_entry.insert(0, "30")
        self.int_time_entry.bind("<Return>", self.set_settings_click)

        self.int_time_show_box = tk.Entry(self.spectrometer_panel, state="readonly")
        self.int_time_show_box.grid(row=0, column=2, padx=10, pady=5, sticky="ew")

        self.set_int_time_btn = tk.Button(self.spectrometer_panel, text="Set", command=self.set_settings_click)
        self.set_int_time_btn.grid(row=0, column=3, padx=5, pady=5)

        self.time_avg_label = tk.Label(self.spectrometer_panel, text="Set Time Average:")
        self.time_avg_label.grid(row=1, column=0, padx=10, pady=5)

        self.time_avg_entry = tk.Entry(self.spectrometer_panel)
        self.time_avg_entry.grid(row=1, column=1, padx=10, pady=5, sticky="ew")
        self.time_avg_entry.insert(0, "1")
        self.time_avg_entry.bind("<Return>", self.set_settings_click)

        self.time_avg_show_box = tk.Entry(self.spectrometer_panel, state="readonly")
        self.time_avg_show_box.grid(row=1, column=2, padx=10, pady=5, sticky="ew")

        self.set_settings_click() # Set initial settings

        self.measure_spectrum = tk.Button(self.spectrometer_panel, text="Measure Spectrum", command=self.measure_spectrum_click)
        self.measure_spectrum.grid(row=3, column=0, padx=10, pady=5)

        self.filename_label = tk.Label(self.spectrometer_panel, text="Filename:")
        self.filename_label.grid(row=2, column=0, padx=10, pady=5)

        self.filename_entry = tk.Entry(self.spectrometer_panel)
        self.filename_entry.grid(row=2, column=1, padx=10, pady=5, sticky="ew")
        self.filename_entry.insert(0, "spectrum")

        self.save_spectrum_btn = tk.Button(self.spectrometer_panel, text="Save Spectrum Data", command=self.save_data_spectrum_click)
        self.save_spectrum_btn.grid(row=3, column=1, padx=5, pady=5)

        self.plot_spectrum_btn = tk.Button(self.spectrometer_panel, text="Save Spectrum Plot", command=self.save_plot_spectrum_click)
        self.plot_spectrum_btn.grid(row=3, column=2, padx=5, pady=5)

        self.show_max_btn = tk.Button(self.spectrometer_panel, text="Display Maximum Value Pixel", command=self.show_max_val_pixel)
        self.show_max_btn.grid(row=3, column=3, padx=5, pady=5)

        self.dark_count_btn = tk.Button(self.spectrometer_panel, text="Measure dark_count", command=self.spec.measure_dark_count)
        self.dark_count_btn.grid(row=4, column=0, padx=10, pady=5)

        # Live Spectrometer View
        self.live_view_active = False
        self.fill = None

        self.fig = Figure(figsize=(5.5, 3), dpi=100)
        self.ax = self.fig.add_subplot(111)
        self.line, = self.ax.plot([], [], color="#2563eb", linewidth=1.2)
        self.ax.set_title("Live Spectrophotometer View", fontsize=14)
        self.ax.set_xlabel("Wavelength (nm)")
        self.ax.set_ylabel("Intensity (counts)")
        self.ax.grid(True, linestyle="--", alpha=0.4)
        self.ax.set_xlim(np.min(self.spec.wavelengths), np.max(self.spec.wavelengths))
        self.ax.set_ylim(0, 2 ** 16)

        self.canvas = FigureCanvasTkAgg(self.fig, master=self.plot_frame)
        self.canvas.get_tk_widget().pack(padx=10, pady=10, fill="both", expand=True)

        self.live_view_btn = tk.Button(self.spectrometer_panel, text="Start Live View", command=self.toggle_live_view)
        self.live_view_btn.grid(row=5, column=0, padx=10, pady=5)

        self.area_label = tk.Label(self.spectrometer_panel, text="Area Under Curve (650-900nm):")
        self.area_label.grid(row=6, column=0, padx=10, pady=5)

        self.area_show_box = tk.Entry(self.spectrometer_panel, state="readonly")
        self.area_show_box.grid(row=6, column=1, padx=10, pady=5, sticky="ew")

    def connect_motor(self):
         self.motor = K10CR2("55547014")
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

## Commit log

2026-08-25 add 3D models
    [25082026_UE3_Des_De_Borger_Motorized_Mount_Holder_v1.stl, Motor_Holder.blend]
2026-08-25 mueller calculus
    [extinction.csv, ultrabbwiregrid.xlsx]
2026-08-26 Cuvette holder
    [26082026_UE3_Des_De_Borger_Cuvette_Holder_v1.stl, 26082026_UE3_Des_De_Borger_Motorized_Mount_Holder_v2.stl]
2026-08-26 spectral composition simulation
    [fresnel_rhomb_data.csv, lin_pol_data.csv]
2026-08-31 max val button
    [wavelength_calibration.xlsx]
2026-09-01 Remove log entry for opacity tool
    Removed entry for 'Print opacity tool' from the log.
2026-09-01 Design front collimator holder
    [20260901_UE3_Des_De_Borger_Collimator_Holder_Front_v1.stl, 20260901_UE3_Des_De_Borger_Enclosure_v2.stl, 20260901_UE3_Des_De_Borger_Opacity_Tool_v1.stl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]
2026-09-01 Add log entry for LASER room filter search
2026-09-02 Add entries for 3D print enclosure fit and design
2026-09-02 alignment experiment
    [20260902_fast_axis_alignment.xlsx, fast_axis_calibration.csv, fast_axis_calibration_fine.csv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]
2026-09-02 Update time for 3D print enclosure fit entry
